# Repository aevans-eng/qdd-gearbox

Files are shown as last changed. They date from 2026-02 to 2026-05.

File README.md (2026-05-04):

# QDD Gearbox

A quasi-direct-drive actuator built around a D6374-150KV BLDC motor, a 5:1 3D-printed planetary gearbox, and an MKS xDrive Mini ODrive-compatible controller. Designed for backdrivability and impedance-control experiments. Total build cost under $120 CAD.

This is a personal engineering project tracked end-to-end with a real V&V framework: requirements, traceability matrix, test plans, and a documented test campaign. The goal is to learn actuator design from the physics up — and to produce something interview-grade for actuator-engineering roles.

## Status

**Rev 00B printed, assembled, and partially validated.**

| Test | Requirement | Status |
|---|---|---|
| T-012 backlash | R-01 | **Pass** — 0° measured |
| T-013 backdrivability | R-04 | Pending hockey-stick adapter |
| BOM weight | R-10 | Pending inspection |
| BOM cost | R-02 | Pending sum |
| T-020 peak torque | R-06 | Pending dyno day |
| T-021 continuous torque | R-07 | Pending dyno day |
| T-022 efficiency | R-09 | Pending — bare-motor baseline blocked, see [`testing/OFFICIAL-DYNO-TESTING.md`](testing/OFFICIAL-DYNO-TESTING.md) |
| T-023 speed | R-11 | Pending dyno day |
| T-024 thermal | R-08 | Pending dyno day |
| Health check (pre/post dyno) | R-05 | Pending |

Active blocker: bare-motor matched-load baseline against the trainer's loaded direction is torque-limited bare-motor. See [session-008 handoff](testing/data/session-008-bare-baseline-handoff.md) for the diagnosis and three options to unblock R-09.

## Hardware

| Component | Spec |
|---|---|
| Motor | D6374-150KV BLDC (7 pole pairs) |
| Torque constant | 0.04 Nm/A (conservative — used for all requirement math; nominal 0.0551 Nm/A documented but not yet re-validated) |
| Controller | MKS xDrive Mini (ODrive-compatible firmware), 8 kHz FOC |
| Gearbox | 5:1 planetary, 3D printed PLA, custom design |
| Supply | 24 V nominal, 10 A current limit, OVP 30 V, OCP 10 A |
| Encoder | Magnetic (integrated with controller) |
| Dyno | Saris H2 / Hammer trainer (BLE power + rpm) |
| Thermal monitoring | Arduino + thermistor on motor body, FET temp from controller |

Direction note: positive motor velocity drives the trainer's *loaded* (resistance-engaged) direction. Negative is freewheel. The bare motor at this controller's effective ~70 A Iq cap (≈ 2.8 Nm) cannot break the trainer's loaded-direction static drag — that's why the gearbox exists.

## How the Test System Works

The dyno runs are *synchronized*: motor controller, BLE dyno, and Arduino temperature logger all start within a second of each other and run for a fixed capture window. Output is one timestamped folder per run with:

- `motor.log` — controller telemetry (vbus, ibus, dc_W, Iq, encoder velocity, FET temp, phase currents)
- `dyno.csv` — Hammer rpm/power/torque from BLE
- `temperature.csv` — Arduino motor-body thermistor
- `manifest.json` — run metadata, parameters, summary stats, exit codes

Run a synced test:

```powershell
cd testing
.\run_official_requirement_test.ps1 -TestStage PreflightDirection
.\run_official_requirement_test.ps1 -TestStage BareBaseline -Series
.\run_official_requirement_test.ps1 -TestStage GearboxEfficiency -Series
```

See [`testing/OFFICIAL-DYNO-TESTING.md`](testing/OFFICIAL-DYNO-TESTING.md) for the full sequence, safety defaults, recovery procedures, and the bare-motor torque-limit constraint.

Compare a bare run against a gearbox-installed run:

```powershell
& C:\Users\aaron\miniconda3\python.exe .\analyze_synced_efficiency.py `
  --bare-run    .\data\synced-official-bare-baseline-40a-YYYYMMDD-HHMMSS `
  --gearbox-run .\data\synced-official-gearbox-efficiency-40a-YYYYMMDD-HHMMSS `
  --rpm-tolerance 3
```

## V&V Framework

11 requirements drive 7 tests + 3 inspections:

- **Source of truth:** [`testing/qdd-rtm.xlsx`](testing/qdd-rtm.xlsx) — full requirements traceability matrix.
- **Test log:** [`testing/validation/test-log.md`](testing/validation/test-log.md) — every test entry with date, config, result, anomalies.
- **Test plans:** [`testing/validation/`](testing/validation/) — per-test procedures, acceptance criteria.
- **Methodology:** test plan was redesigned around a V-model approach in March 2026.

Every test session also gets a journal entry in [`testing/data/session-log.md`](testing/data/session-log.md) and, for major sessions, a handoff doc (`session-NNN-*-handoff.md`) capturing what worked, what didn't, and what the next session needs to know.

## Repo Structure

```
calc/                 Python design calculators (gear geometry, tooth stress, bearing life, thermal)
docs/
  design/             Tolerances, assembly profile, gear parameters
  catia/              CATIA modeling guide and skeleton workflow
  log/                Session work logs
drawings/             GD&T annotation notes
prototypes/
  rev00a/             First print — superseded
  rev00b/             Current revision (assembled, partial validation passed)
testing/
  OFFICIAL-DYNO-TESTING.md     Operating procedures for the dyno campaign
  qdd-rtm.xlsx                 Requirements traceability matrix
  run_official_requirement_test.ps1   Wrapper for each requirement test stage
  run_synced_motor_dyno_temp.ps1      Underlying synced-capture orchestrator
  analyze_synced_efficiency.py        Match bare vs gearbox runs at common rpm windows
  plot_synced_run.py                  Per-run timeseries plots
  mks-xdrive-mini/                    Controller-side scripts and session checklist
  temperature-logger/                 Arduino + Python thermistor logger
  dyno/ble-capture/                   BLE Hammer capture
  validation/                         Per-test plans, test log, methodology docs
  hardware/                           Safety checklist, SOP, mounting notes
  data/                               Run folders + session-log.md + handoff docs
  future-work.md                      Characterization and controls ideas
STATE.md              Current project state — start here for any new session
CLAUDE.md             Project rules and conventions
```

## Active Files to Read First

- **[STATE.md](STATE.md)** — current status, remaining tests, file map, blockers.
- **[testing/data/session-008-bare-baseline-handoff.md](testing/data/session-008-bare-baseline-handoff.md)** — most recent test session, harness bug fixes, R-09 unblock options.
- **[testing/OFFICIAL-DYNO-TESTING.md](testing/OFFICIAL-DYNO-TESTING.md)** — dyno operating procedures.
- **[testing/qdd-rtm.xlsx](testing/qdd-rtm.xlsx)** — requirements ↔ tests matrix.

## License

Personal learning project. Not intended for redistribution.

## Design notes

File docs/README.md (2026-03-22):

# QDD Gearbox — Docs Index

## Design Reference
- `design/assembly-profile.md` — Assembly overview (living doc)
- `design/tolerance-scheme.md` — Tolerance scheme + FDM offsets
- `design/cycloidal-gear-params.md` — Involute vs cycloidal reference
- `design/motor-fastener-specs.md` — Motor fastener M3/M4 specs
- `design/tolerancing-discussion.md` — Assembly interface Q&A
- `design/non-parametric-shortcuts.md` — Hardcoded prototype decisions to fix later
- `design/manufacturing-tips.md` — DFM lessons

## CATIA Workflows
- `catia/step-integration.md` — STEP import workflow (the main doc)
- `catia/modeling-guide.md` — Modeling principles + assembly structure
- `catia/skeleton-workflow.md` — Practical skeleton workflows
- `catia/skeleton-step-current-state.md` — Confirmed STEP geometry values
- `catia/params-2026-02-20.txt` — Skeleton parameter dump (raw)

## Other
- `log/` — Dated work log entries
- `images/` — Screenshots and diagrams
- `original-documentation-jan4/` — Original design sprint docs (requirements, trade studies, etc.)
- `_archive/` — Old numbered docs (01-09), superseded

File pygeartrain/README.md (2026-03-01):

# pygeartrain



Python library for gear train calculations, visualizations, optimizations, and CAD profile export.

## Features

*   Symbolic calculation of gear ratios for various geartrain types.
*   Generation of 2D gear profiles (cycloidal, epi/hypo mix, involute - WIP).
*   Visualization and animation of geartrain kinematics using Matplotlib.
*   Export of gear profiles coordinates suitable for CAD import (e.g., SolidWorks).
*   Support for standard planetary, compound planetary (Wolfram), cycloidal, compound cycloidal, Nabtesco-style, and angular contact drives.

## Examples

Some examples of currently implemented gear trains:

**Compound Planetary (High Ratio)**<br />
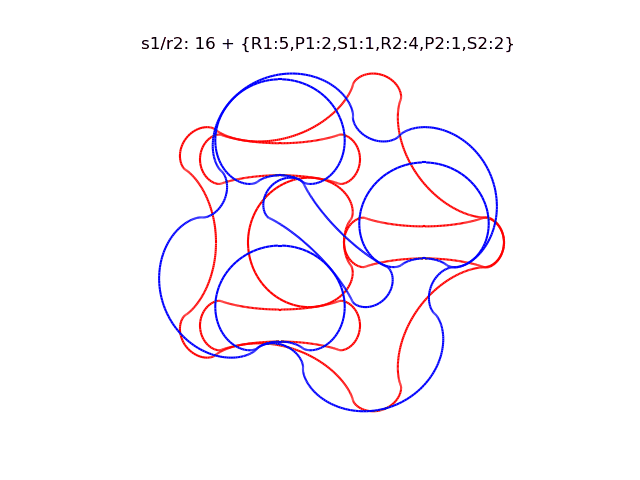
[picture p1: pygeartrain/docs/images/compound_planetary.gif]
Compound Planetary (High Ratio)
<br />

**Compound Planetary (Printable Low Count)**<br />
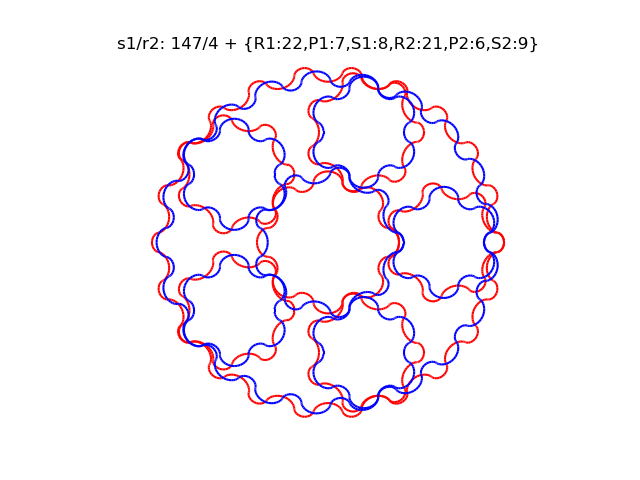
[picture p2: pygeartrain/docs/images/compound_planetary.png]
Compound Planetary (Printable Low Count)
<br />

**Angular Contact Drive**<br />
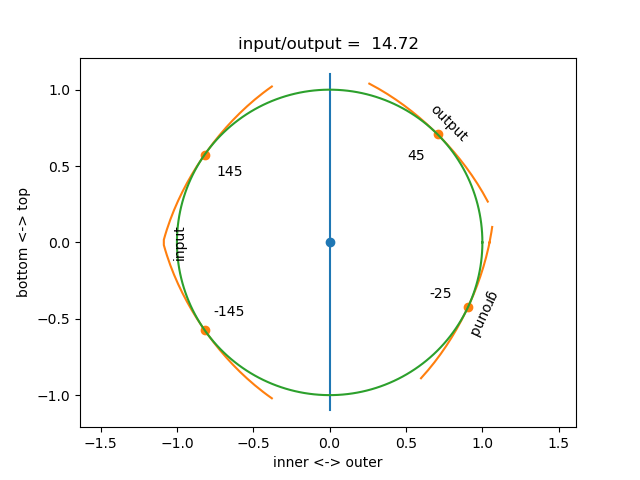
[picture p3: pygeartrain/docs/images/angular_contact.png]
Angular Contact Drive
<br />

**Cycloidal Drive**<br />
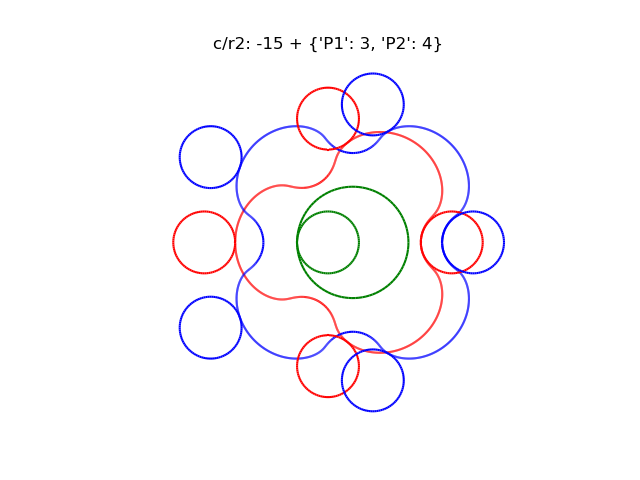
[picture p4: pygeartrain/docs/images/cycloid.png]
Cycloidal Drive
<br />

## Installation & Environment Setup

This project uses Conda for environment management.

**Prerequisites:**
*   [Conda](https://docs.conda.io/en/latest/) (Miniconda is recommended: [https://docs.conda.io/en/latest/miniconda.html](https://docs.conda.io/en/latest/miniconda.html))
*   [Git](https://git-scm.com/) (for cloning the repository)

**Steps:**

1.  **Clone the repository:**
    ```bash
    git clone https://github.com/CKraft11/pygeartrain pygeartrain
    cd pygeartrain
    ```

2.  **Create the Conda Environment:**
    Open your terminal or Anaconda Prompt in the `pygeartrain` directory (where `environment.yml` is located) and run:
    ```bash
    conda env create -f environment.yml
    ```
    *(Optional, faster alternative if you have Mamba installed: `mamba env create -f environment.yml`)*

3.  **Activate the Environment:**
    Each time you want to work with this project in a new terminal session, activate the environment:
    ```bash
    conda activate pygeartrain
    ```
    You should see `(pygeartrain)` appear at the beginning of your terminal prompt.

## Basic Usage: Calculating Ratios

You can define the kinematics of a geartrain and calculate its ratio symbolically:

```python
from pygeartrain.planetary import Planetary

# Define kinematics: Input='s' (sun), Output='c' (carrier), Fixed='r' (ring)
kinematics = Planetary('s', 'c', 'r')

# Print the kinematic definition and the calculated ratio formula
print(kinematics)
# >>> s/c: (R + S)/S
```

## Advanced Usage: Generating CAD Profiles for SolidWorks

Right now I've made `generate_planetary_cad.py` which only works for planetary gears. Generating the other gear types shouldn't be too hard following this script.

**1. Configuration:**

   Open the `generate_planetary_cad.py` script in a text editor. Modify the parameters in the "**User Defined Parameters**" section near the top:

   *   `TARGET_RING_DIAMETER_MM`: Set the desired outer diameter (in mm) for the final scaled ring gear. All other gears are scaled proportionally.
   *   `GEAR_THICKNESS_MM`: Set the total face width (along the Z-axis) for the gears.
   *   `HELIX_ANGLE_DEGREES`: Define the helix angle (in degrees) for one side of the gear tooth (used for both helix and herringbone).
   *   `GEAR_TYPE`: Choose `'helix'` for standard helical gears or `'herringbone'` for double-helical (V-shaped) gears.
   *   `R_teeth`, `P_teeth`, `S_teeth`: Set the tooth counts for the Ring, Planet, and Sun gears. Ensure they satisfy the planetary assembly condition: `R = S + 2*P`.
   *   `N_planets`: Set the number of planet gears around the sun.
   *   *(Optional)* `b_profile`: Adjust the epi/hypo cycloid mix ratio (0 to 1) for the tooth shape.
   *   *(Optional)* `CARRIER_PATH_POINTS`: Number of points for the exported circular carrier path file.
   *   *(Optional)* `CLOSE_POINT_TOLERANCE`, `SMALL_RADIUS_TOLERANCE`: Adjust point filtering sensitivity if needed.

**2. Running the Export Script:**

   Make sure the `pygeartrain` environment is active (`conda activate pygeartrain`). Run the script from the main project directory:

   ```bash
   python generate_planetary_cad.py
   ```

**3. Understanding the Output:**

   The script will create a directory named `output_helix` or `output_herringbone` containing several `.txt` files:

   *   **Gear Profile Curves:** 9 files for the gear teeth, 3 for each gear type (ring, planet, sun).
        *   `*_z0.txt`: The profile curve at the center plane (Z=0).
        *   `*_z_pos.txt`: The profile curve twisted for the +Z face (at Z = +thickness/2).
        *   `*_z_neg.txt`: The profile curve twisted for the -Z face (at Z = -thickness/2).
        *(The twist direction and type depend on the `HELIX_ANGLE_DEGREES` and `GEAR_TYPE` settings, with meshing hands automatically adjusted).*
   *   **Carrier Path:** 1 file:
        *   `carrier_path.txt`: A simple circle representing the path of the planet gear centers, useful for positioning planets in an assembly. Lies in the Z=0 plane.

   All coordinates in the files are in millimeters, scaled according to `TARGET_RING_DIAMETER_MM`.

**4. Importing into SolidWorks:**

   *  Create a new SolidWorks Part file.
   *  Import the 3 curves for **one gear** (e.g., `ring_21_z_neg.txt`, `ring_21_z0.txt`, `ring_21_z_pos.txt`):
       *   Go to **Insert > Curve > Curve Through XYZ Points**.
       *   **Browse** and select the first file (e.g., `_z_neg.txt`). Click **OK**.
       *   Repeat for the `_z0.txt` and `_z_pos.txt` files of the *same gear*. The curves should appear positioned correctly in 3D space.
   *  Select the three imported curves for that gear in the FeatureManager Design Tree.
   *  Click point in reference geometry and select one of the imported curves (do this for all 3 curves)
   *  Create a 3D sketch with two lines between the 3 points you just added in order to create a loft guide. You shoud have something looking like this.
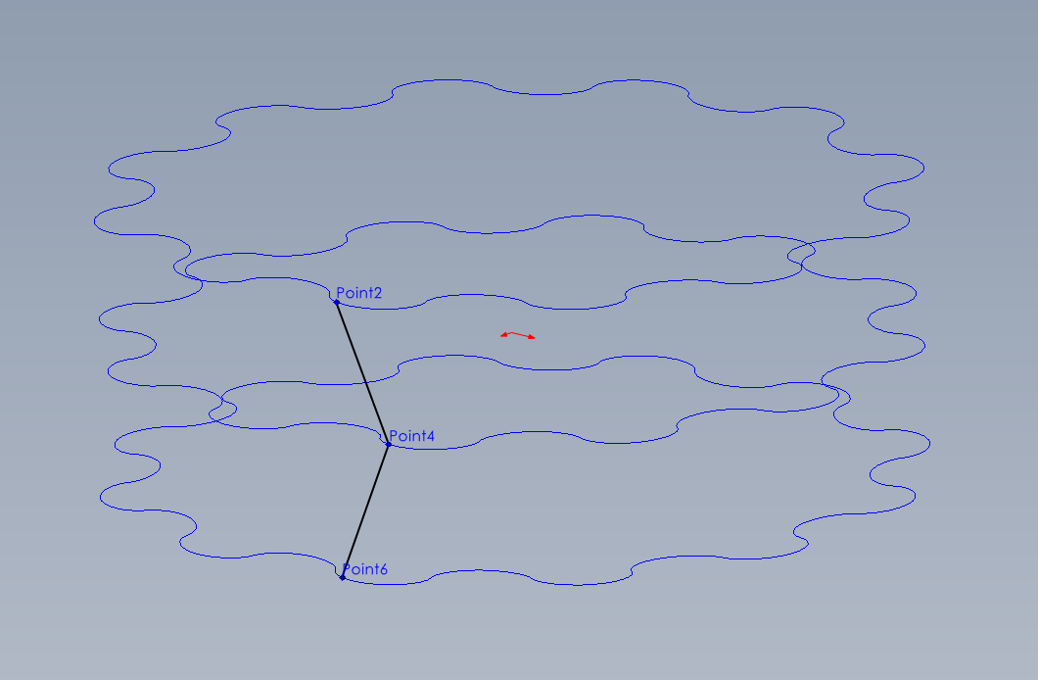
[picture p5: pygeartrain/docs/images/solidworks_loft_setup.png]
Solidworks Loft Setup
   
   *  Create the gear body by creating two lofts separatly for either side using **Insert > Boss/Base > Loft** (or **Insert > Surface > Loft**). Use the 3D sketch as a guide for both of them.
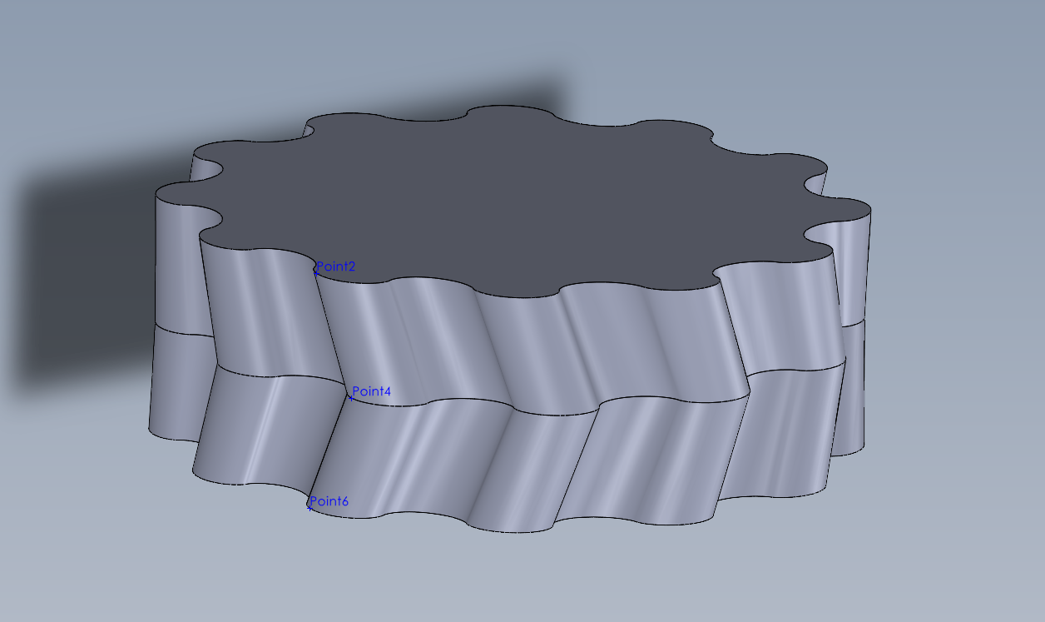
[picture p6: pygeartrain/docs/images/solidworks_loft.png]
Solidworks Loft Setup
   
   *  Repeat steps for the Sun and Planet gears using their respective curve files.
   *  **For the Planet:** After creating the single lofted planet gear body, use the **Circular Pattern** feature (**Insert > Pattern/Mirror > Circular Pattern**) to create `N_planets` instances around the part origin.
   *  **Carrier Path (Optional):** Import `carrier_path.txt` onto a sketch on the Front Plane (Z=0) using **Insert > Curve > Curve Through XYZ Points**. Solidworks doesnt recognize this as a circle so you can create a circle on the XY plane and set it to have a point coincident to the carrier path curve. This circle can be used as a construction reference for designing the physical carrier or for assembly mates.

## Animation

The geometry objects generated by the library (like `PlanetaryGeometry`) often have an `.animate()` method. You can call this in your script (after creating the `gear` object) to visualize the kinematic motion using Matplotlib.

```python
# Assuming 'gear' is a created PlanetaryGeometry object
# gear.animate() # Call this instead of static plotting
# plt.show() # Not needed if calling animate()
```

*Note: The animation shows the **unscaled** gear profiles to verify meshing and relative speeds based on the kinematics.*

## License

This project is licensed under the MIT License - see the [LICENSE](LICENSE) file for details.

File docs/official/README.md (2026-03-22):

# Official Documentation

Portfolio-ready and publication-ready content for the QDD Gearbox project.

| File | Purpose |
|---|---|
| `website-content-bank.md` | Consolidated text content for the portfolio page — all sections, tables, specs |
| `media-next-steps.md` | Checklist of photos, renders, graphs, and diagrams still needed |

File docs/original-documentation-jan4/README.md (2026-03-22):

# Design Sprint — Jan 4, 2026

Organized reference from the original hackathon Google Doc where the QDD actuator project was scoped, designed, and kicked off in a single day.

## Contents

| File | What's in it |
|---|---|
| `goals-and-scope.md` | Project objectives, definition of done, in/out scope |
| `design-requirements.md` | Ranked priorities, quantified metrics, hard vs soft requirements |
| `systems-and-interfaces.md` | System block diagram, subsystem definitions, interface strategy |
| `trade-studies.md` | Pugh matrices for reduction method, gear ratio, and bearings |
| `design-process.md` | The step-by-step design process used that day |
| `parts-list.md` | Fasteners, bearings, tools — what was sourced |
| `prototype-strategy.md` | 3D modeling strategy, assembly stack, initial design notes |
| `references.md` | External links |

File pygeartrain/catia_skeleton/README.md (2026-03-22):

# CATIA Planetary Gearbox Skeleton Generator

Creates reference geometry for planetary gearbox design in 3DExperience CATIA.

## Status: WORKING

![[photos/skeleton-working-result.png]]
*Wireframe skeleton*

![[photos/skeleton-with-cylinders.png]]
*Solid cylinders generated from skeleton*

## Workflow

| Version | File | Purpose | Status |
|---|---|---|---|
| **Bounding Cylinders** | `PlanetarySkeletonGenerator.bas` | Quick visualization with solids | Untested |
| **True Skeleton** | `PlanetarySkeletonTrue.bas` | Wireframe for skeleton-first design | **WORKING** |

**Recommendation:** Use True Skeleton for any real design work.

## Key Learnings (2026-01-31)

### 3DExperience VBA Differences

1. **Get active part:** Use `CATIA.ActiveEditor.ActiveObject` (NOT `CATIA.ActiveDocument`)

2. **Create circles:** `AddNewCircleCtrRad` requires 4 arguments:
   ```vba
   ' WRONG (3 args - fails silently)
   hsFactory.AddNewCircleCtrRad(center, plane, radius)

   ' CORRECT (4 args - geodesic boolean required)
   hsFactory.AddNewCircleCtrRad(center, plane, False, radius)
   ```

3. **Create axes:** `AddNewLinePtDir` works with 5 args:
   ```vba
   hsFactory.AddNewLinePtDir(point, direction, startLength, endLength, False)
   ```

4. **Direction from plane:** Get Z-direction by passing XY plane to `AddNewDirection`:
   ```vba
   Set dirZ = hsFactory.AddNewDirection(part.OriginElements.PlaneXY)
   ```

## Files

| File | Purpose |
|---|---|
| `PlanetarySkeletonTrue.bas` | Step 1: Creates wireframe skeleton |
| `SkeletonToCylinders.bas` | Step 2: Pads circles into solid cylinders |
| `PlanetarySkeletonGenerator.bas` | Alt: Bounding cylinders (untested) |
| `Skeleton Generator Walkthrough.md` | Detailed usage guide |
| `photos/` | Screenshots |

## Quick Start

1. Open a new **3D Part** in 3DExperience
2. Make sure part is in edit mode (double-click if needed)
3. Press `Alt+F8` → Macros → Select → `PlanetarySkeletonTrue.bas` → Run
4. Run again with `SkeletonToCylinders.bas` to create solid bodies

### Generated Geometry

```
Skeleton (Geometrical Set)
├── POINT_ORIGIN
├── AXIS_SUN
├── CIRCLE_PITCH_SUN (r=7mm)
├── CIRCLE_PITCH_RING (r=35mm)
├── CIRCLE_OUTER_RING (r=40mm)
├── CIRCLE_ORBIT (r=21mm)
├── POINT_PLANET_1, _2, _3
├── AXIS_PLANET_1, _2, _3
└── CIRCLE_PITCH_PLANET_1, _2, _3 (r=14mm)
```

### Customizing Dimensions

Edit these variables at the top of the macro:
```vba
Dim SunPD As Double: SunPD = 14       ' Sun pitch diameter
Dim PlanetPD As Double: PlanetPD = 28 ' Planet pitch diameter
Dim RingPD As Double: RingPD = 70     ' Ring pitch diameter
Dim RingOD As Double: RingOD = 80     ' Ring outer diameter
Dim OrbitR As Double: OrbitR = 21     ' = (SunPD + PlanetPD) / 2
```

## Planetary Gear Validation

For proper mesh: `RingTeeth = SunTeeth + 2 × PlanetTeeth`

Example (HackathonActuator): 30 = 6 + 2×12 ✓

## Roadmap

### Next: Additional Components
- [ ] Carrier disc with planet bores
- [ ] Carrier pins (cylinder at each planet axis)
- [ ] Bearing cylinders (ID/OD representation)
- [ ] Input/output shaft cylinders

### Future: Parametric Enhancements
- [ ] CATIA parameters (edit in tree instead of macro)
- [ ] Formulas for derived dimensions
- [ ] Publications for external linking
- [ ] Top/bottom planes for extrusion limits

## Related

- [[CATIA XYZ Import Progress]] - Import actual gear tooth profiles
- [[HackathonActuator]] - Gearbox this was developed for

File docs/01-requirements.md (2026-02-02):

# QDD Actuator — Design Requirements

## Project Goal

Create a quasi-direct-drive actuator by designing a 3D-printable gearbox to interface with a BLDC motor, magnetic encoder, and ODrive controller.

## Primary Objective

Reach "Manufacturing Readiness" — complete CAD assembly, locked BOM, and all COTS components ordered.

## Secondary Objective

Complete "Design Intent" documentation (justification for ratio, motor choice, materials).

## Scope

### In-Scope

- Mechanical design of a reduction stage (gearbox) optimized for FDM 3D printing
- Integration of a specific BLDC motor, magnetic encoder, and ODrive controller
- Interface design of the housing and output interface
- Basic modeling of the control system

### Out-of-Scope

- Custom motor winding or controller PCB design
- Complex firmware coding (basic ODrive config is assumed)
- Exotic manufacturing (no CNC aluminum; design must be printable)

## Performance Requirements (Ranked by Priority)

| # | Requirement | Metric | Hard/Soft |
|---|---|---|---|
| 1 | Low Backlash | ≤ 0.5° of backlash | Hard |
| 2 | Low Cost | Under $120 CAD | Hard |
| 3 | DFM/DFA | All off-the-shelf + 3D printed parts. No complex tools for assembly | Hard |
| 4 | Quasi-Direct Drive | Backdriveable under human impulse loading | Hard |
| 5 | High Durability | Cannot break itself in under 1 minute (SW + HW limits) | Hard |
| 6 | Peak Torque | ≥ 16 Nm peak | Hard |
| 7 | Continuous Torque | ≥ 12 Nm continuous | Hard |
| 8 | Output Integration | Supports shafts or bolted plates | Soft |
| 9 | Thermal Performance | No melting in < 5 minutes | Hard |
| 10 | Efficiency | > 90% | Soft |
| 11 | Weight | Under 2 kg | Soft |
| 12 | RPM Range | ≥ 600 RPM continuous | Soft |

## What Makes a QDD Different

A QDD is not a regular geared motor. If the gearbox has high friction or backlash, it is not a QDD — it must be backdrivable. **Transparency** and **backlash** are the defining characteristics.

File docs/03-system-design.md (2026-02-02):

# QDD Actuator — System Design

## System Block Diagram

Power Supply → ODrive ESC → BLDC Motor → Input Coupling → Gear Reduction → Output Coupling → Load
                  ↑
               Encoder (feedback to ESC)
               Brain (commands to ESC)

## Subsystem Definitions

### Power Supply
- **Input:** Wall power
- **Purpose:** Provide electrical power to ESC
- **Output:** Conditioned DC power to ESC

### Brain
- **Purpose:** Tells the ESC what to do
- **Input:** User commands
- **Output:** Signal to ESC

### ODrive ESC
- **Purpose:** Control motor
- **Input:** Conditioned DC power, signal from brain
- **Output:** Motor winding current

### BLDC Motor
- **Purpose:** Torque to coupling
- **Input:** Current from ESC
- **Output:** Torque

### Encoder
- **Purpose:** Sensing for control system
- **Input:** Coupled to motor
- **Output:** Signal to ESC

### Input Coupling
- **Purpose:** Couples motor to gearbox
- **Input:** Motor shaft
- **Output:** Gearbox input
- **Options considered:** Press fit, screw collar, keyed shaft

### Gear Reduction
- **Purpose:** Increase torque
- **Input:** Coupling
- **Output:** Output coupling

### Output Coupling
- **Purpose:** Control output arm
- **Input:** Gearbox output
- **Output:** Control arm
- **Considerations:** Size, fastening methods, supported vs unsupported bearing interaction

## Critical Interfaces

1. **Thermal Interface:** Motor to mount
2. **Mechanical Interface:** Output shaft to load
3. **Data Interface:** Magnet position relative to encoder chip

## Control Strategy

Confirm ODrive control mode (Position vs. Velocity vs. Torque) matches the mechanical design. Verify encoder resolution is sufficient for the gear reduction.

## Key Design Lesson

> The #1 failure mode in student robotics projects is not the gearbox itself, but how the gearbox attaches to the motor or how the magnet attaches to the shaft. — Interface definition is critical.

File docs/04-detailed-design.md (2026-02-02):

# QDD Actuator — Detailed Design & CAD

## 3D Modeling Strategy

- Master assembly designed to be modular with different gearing layouts, minimizing iteration time
- Sun, planet, and ring gears are interlinked but should be independent systems
- Carrier designed to be parametric with the gear systems — always compatible
- Ring gear modular from gearbox housing — easily swappable for prototyping
- Housing may need two parts: ring gear installs into housing, carrier sits under planets
- Sun, planet, and ring to be printed together

## Assembly Stack (Bottom → Top)

1. Bottom housing face
2. Housing bottom carrier bearing
3. Bottom carrier plate
4. Sun gear on shaft, planet gears aligning with bottom carrier plate and pins, ring gear slides into housing
   - Planet gears
5. Top carrier plate
6. Ring gear locking feature
7. Lid top carrier bearing
8. Lid

## Parts to Design

- Housing that bolts to motor
- Sun gear that interfaces with motor output
- Planet gears
- Ring gear with output connection
- Lid

## Design for Manufacturing (DFM)

- Apply printing tolerances (offsets)
- Design orientation features (avoid supports on gear faces)
- Virtual assembly in CAD to catch interference

## Design Calculators Needed

- Bearing placement calculator
- Bearing lifetime calculator
- Involute teeth stress calculator
- Cycloidal teeth stress calculator
- Shear on pins/screws calculator

## CAD Creation Pipeline (Parallel Tasks)

1. Get gear teeth generator working
2. Make arbitrary gearset to try out different input and output strategies

## Design Decision: 5:1 Ratio Maintained

Decision was made to maintain 5:1 gear ratio based on trade study results (see 02-trade-studies.md).

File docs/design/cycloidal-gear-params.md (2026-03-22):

# Cycloidal Gear Parameter Reference

How to think about cycloidal planetary gear dimensions when coming from an involute background.
Applies to this project: R48/P18/S12, pygeartrain, herringbone, scaled to 75mm ring ID.

---

## Involute vs Cycloidal — Parameter Comparison

| Parameter | Involute | Cycloidal |
|---|---|---|
| **Module** | $m$ — sets tooth scale, $d = m \times N$ | **N/A — delete this parameter.** Tooth scale is set by specifying ring diameter + tooth counts. Do not set to zero (breaks formulas). |
| **Pitch diameter** | Clean definition: $d = m \times N$, the reference circle where teeth mesh | No clean equivalent. Use **outer diameter (tip circle)** as the functional reference for skeleton checks. Carrier radius = `(ring_pitch_diam - planet_outer_diam) / 2` — planet tips are tangent to ring tooth roots which sit at the pitch reference. |
| **Tooth depth** | $2.25m$ (standard full depth) | Falls out of rolling circle geometry. Cannot be calculated from a simple formula — **measure from STEP in CATIA.** |
| **What sets the scale** | Module | Target ring inner diameter + tooth counts (R, P, S) |
| **What you specify** | $m$, $N$, pressure angle | $R$, $P$, $S$, ring diameter, face width |

---

## This Project's Dimensions (Run 001 STEP files)

From `generate_step_aaron.py` output and `catia/step-integration.md`:

| Part | Dimension | Value | What it is |
|---|---|---|---|
| Sun | Outer diameter | 19.9mm | Tip circle — largest solid extent |
| Planet | Outer diameter | 29.1mm | Tip circle — largest solid extent |
| Planet | Center-to-axis distance | 23.0mm | Carrier radius — where planet center sits |
| Ring | Inner reference diameter | 75.0mm | Pitch reference / engagement zone |
| Ring | Outer diameter | 95.0mm | OD — fits in housing bore (95.3mm, 0.3mm clearance) |
| Ring | Nominal wall | 10.0mm | From 75mm ID reference to 95mm OD — **includes tooth depth** |
| Ring | Solid wall (root to OD) | **Measure in CATIA** | Less than 10mm — see below |
| All gears | Face width | 18.6mm | Axial thickness |

---

## The Ring Gear Wall Problem

`RING_WALL_MM = 10mm` in the script is measured from the **pitch reference radius (37.5mm) to the outer cylinder (47.5mm).**

The tooth roots cut *outward* from the pitch reference, eating into that 10mm. The actual solid wall between the deepest tooth root and the OD is less than 10mm.

**To get the real solid wall:**
1. Import `gearbox_CAD.step` into CATIA
2. Section view through the ring gear (section on the gear midplane)
3. Pick a tooth root face (the outermost point of the internal tooth profile)
4. Measure radial distance from that face to the OD cylinder
5. Record that number — it's the minimum solid wall for fastener and structural design

**Why this matters for the skeleton:**
- Fastener holes through the ring wall must stay radially outside the tooth root circle
- The skeleton parameter `ring_wall_thickness = 10mm` is the nominal design wall, not the solid wall
- Don't position fastener hole centers using 10mm as the solid material — wait for the STEP measurement

---

## Skeleton Parameter Updates (Old Involute → New Cycloidal)

Changes to make in SKEL_Gearbox before importing STEP:

| Skeleton Param | Action | New Value | Priority |
|---|---|---|---|
| `planet_mid_path` | Update | **23.0mm** | Critical — drives bearing pocket placement |
| `planet_pitch_diam` → rename to `planet_outer_diam` | Update | **29.1mm** | Important — drives clearance checks |
| `sun_pitch_diam` → rename to `sun_outer_diam` | Update | **19.9mm** | Minor — 0.1mm change |
| `gear_module` | **Delete** | N/A | Do not set to zero |
| `ring_pitch_diam` | No change | 75mm | Already correct |
| `gear_height` | No change | 18.6mm | Already correct |
| `ring_wall_thickness` | No change (for now) | 10mm | Verify actual solid wall after STEP import |
| `housing_ring_gear_bore` | No change | 95.3mm | Already correct |

---

## Notes

- For pygeartrain cycloidal gears, "pitch diameter" and "outer diameter" are not the same thing, but outer diameter is the useful number for physical fit checks in CATIA.
- The gear ratio is still $\frac{R + S}{S} = \frac{48 + 12}{12} = 5:1$ — same math as involute.
- Tooth counts R/P/S fully define the geometry proportions; ring diameter sets the scale.

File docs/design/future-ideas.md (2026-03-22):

# Future Design Ideas

Notes on potential improvements for future revisions.

## Slimmer Bearing → Smaller Housing
- Switch bottom bearing to a thinner, wider variant
- Reduces total gearbox height
- **Must verify:** radial stress and fatigue via hand calcs
- **Constraint:** lower bearing cannot interfere with fastener threads

## Ring Gear as Housing ("Hamburger" Layout)
- Drop housing walls down to same diameter as ring gears
- Ring gears become the structural middle of the gearbox (like a hamburger patty)
- Eliminates the current approach of ring gear sitting *inside* the housing
- Combined with slimmer bearings, significantly reduces form factor

## Carrier Fastening & Planet Shaft Strategy
- **Option A: Shoulder bolts** — dual-purpose as carrier half constraints and planet bearing shafts
- **Option B: Pins + fasteners** — dedicated pins for planet bearing shafts, separate fasteners to connect carrier halves
- Worth exploring trade-offs (assembly complexity, tolerance stack, load path, part count)

## Integrated Motor + Controller Package
- Future iteration: combine gearbox with a 3D-printed motor housing
- Single package houses motor controller, brake resistor, and encoder

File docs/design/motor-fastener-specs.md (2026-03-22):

Motor housing-lid fasteners
m3 x 8mm, cap head (-motor housing)
- 5mm thread engagement
- Head height is 3.25mm
- available lengths: 8mm, 12mm, 16mm, 20mm
- 
m4 x 6mm button head (-motor)
- 4mm thread engagement 
- Head height is 3.5mm
- MAX THREAD ENGAGMENT SHOULD BE 4mm, longer threads can result in damage to motor
- at most counterbore should be baseheight - counterbore = (fastener length-engagement), counterbore = baseheight +engagement - fastener length

with 6mm lid height
4mm m4 counterbore
3mm m3 counterbore

currently, the fastener holes for body to motor and motor housing are NOT parametric.

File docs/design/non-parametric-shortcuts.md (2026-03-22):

# Non-Parametric Shortcuts — Prototype Debt

Things hardcoded or done in haste for the prototype that will break if design parameters change. Fix these before any serious design iteration.

---

## Gear Cutting Bodies — Hardcoded to 3 Planets

The `cutting/adding bodies` part has 3 separate cutting body entities, one per planet. CATIA can't (as far as we know) apply one cutting body to multiple target entities, so the count is manually matched to `number_of_planets = 3`.

**Breaks if:** planet count changes (e.g. 4 planets → need a 4th cutting body manually added).

**Proper fix:** Investigate if CircPattern or body-level patterning can drive cutting bodies from `number_of_planets`. If not, at minimum document the manual step clearly so it's not forgotten during a redesign.

---

## Housing Base Fasteners — Fixed Counts

Some housing base fastener holes are set to fixed numbers rather than driven by a parameter or pattern.

**Breaks if:** fastener layout changes (different bolt count or pattern).

**Proper fix:** Drive from skeleton parameter + circular/rectangular pattern.

---

## Motor Housing Fasteners — Not Parametric

From `motor-fastener-specs.md`: "currently, the fastener holes for body to motor and motor housing are NOT parametric."

**Breaks if:** motor changes, lid thickness changes, or fastener spec changes.

---

*Add more shortcuts here as you notice them. Review before any major design change.*

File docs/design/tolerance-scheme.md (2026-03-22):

# Tolerance Scheme — QDD Planetary Gearbox

Every mating interface in the gearbox, with fit types, tolerance values, and critical stack-ups. Bridges ISO/ASME fit standards (for learning) with FDM-practical values (for implementation).

**Status:** Post-calibration v1 — applying coupon results to CATIA parameters. Planet gear print queued to validate bearing bore offset with a real part. Small hole offsets are approximate — planet print tests the critical bearing fit, remaining small features validated later.

**Key design facts (from discussion):**
- Lid step presses down onto ring gears (axial constraint)
- Ring gears slide into cylindrical housing bore, split at mid-height
- Shoulder screws = planet pins + carrier fasteners
- Carrier sits on bottom main bearing via lip; lid bearing catches top carrier
- Sun gear: press fit onto D-shaft (circle with flat)
- Herringbone planets: self-centering axially, floating
- No post-processing planned — everything as-printed
- Calibration coupon v1 printed 2026-02-19 — main bearing fit validated, planet bore and small holes need offset corrections
- CATIA parameters being updated with calibration-derived offsets (2026-02-20)

**Related docs:**
- `_archive/08-gdt-notes.md` — Datum reference frame and GD&T callouts
- `_archive/05-parts-list.md` — BOM with bearing/fastener specs
- `tolerancing-discussion.md` — Design Q&A (completed)

---

## Background: How ISO Fits Work

If you've never worked with ISO tolerance designations before, this section explains the system. Everything below in the interface tables will make more sense after reading this.

### The Problem Fits Solve

When two parts mate — a shaft going into a hole — you need to control how tight or loose that joint is. Too loose and things rattle. Too tight and you can't assemble it (or you crack the part). The ISO system gives engineers a standardized language to specify exactly how much clearance or interference a joint should have.

### Anatomy of a Designation: H7/k6

Every fit designation has two parts: **hole / shaft**.

```
    H  7  /  k  6
    │  │     │  │
    │  │     │  └── Tolerance grade (how precise the shaft must be)
    │  │     └───── Fundamental deviation (where the shaft sits relative to nominal)
    │  └────────── Tolerance grade (how precise the hole must be)
    └───────────── Fundamental deviation (where the hole sits relative to nominal)
```

### The Letter: Fundamental Deviation (Position)

The letter tells you **where** the tolerance zone sits relative to the nominal (exact) dimension.

**For holes** (uppercase letters):
```
                     Nominal
                        │
  A  B  C  D  ... G  H │ J  K  ... N  P  R  S  ...  Z
  ◄─── larger ─────────►│◄─── smaller ──────────────►
        (more clearance) │      (more interference)
```

**For shafts** (lowercase letters):
```
                     Nominal
                        │
  a  b  c  d  ... g  h │ j  k  ... n  p  r  s  ...  z
  ◄─── smaller ────────►│◄─── larger ──────────────►
        (more clearance) │      (more interference)
```

**Key letters to know:**

| Letter | Meaning |
|---|---|
| **H** (hole) | Starts exactly at nominal, goes up. The most common hole designation — "hole basis" system |
| **h** (shaft) | Starts exactly at nominal, goes down. Shaft at or below nominal |
| **g** (shaft) | Below nominal — guaranteed clearance in an H hole |
| **k** (shaft) | Straddles nominal — might be slightly above or below. Transition zone |
| **p** (shaft) | Above nominal — guaranteed interference in an H hole |

### The Number: IT Grade (Precision)

The number (called the **IT grade**) controls **how wide** the tolerance band is — i.e., how precisely the part must be made.

| IT Grade | Typical Tolerance at ⌀25mm | Used For |
|---|---|---|
| IT5 | ±0.004mm | Precision ground shafts |
| IT6 | ±0.006mm | Ground/precision turned shafts |
| IT7 | ±0.010mm | Reamed holes, good machining |
| IT8 | ±0.013mm | Standard machining |
| IT11 | ±0.065mm | Rough machining |
| IT14+ | ±0.26mm+ | Sheet metal, casting, **FDM printing** |

**Lower number = tighter tolerance = more expensive to make.**

For our QDD project, standard machining fits (IT6/IT7) describe what we *want* the joint to behave like. The FDM offsets in this doc are how we *approximate* those fits with 3D printing.

### The Three Fit Categories

When you combine a hole and shaft designation, you get one of three fit types:

```
  ┌──────────────┬──────────────┬──────────────┐
  │  CLEARANCE   │  TRANSITION  │ INTERFERENCE  │
  │              │              │               │
  │  Shaft       │  Shaft       │   ████████    │
  │  ┌──────┐    │  ┌───╫──┐   │  ┌██████──┐   │
  │  │      │    │  │   ║  │   │  │████████ │   │
  │  │ gap  │    │  │   ║  │   │  │████████ │   │
  │  │      │    │  │   ║  │   │  │████████ │   │
  │  └──────┘    │  └───╫──┘   │  └██████──┘   │
  │   Hole       │   Hole       │   Hole        │
  │              │  may be      │   shaft is    │
  │  always a    │  clearance   │   larger      │
  │  gap         │  or press    │   than hole   │
  └──────────────┴──────────────┴──────────────┘
```

| Category | Example | Shaft vs Hole | Typical Use |
|---|---|---|---|
| **Clearance** | H7/g6 | Shaft always smaller | Sliding/rotating parts, easy assembly |
| **Transition** | H7/k6 | Could go either way | Locating bearings in stationary housings |
| **Interference (Press)** | H7/p6 | Shaft always larger | Locking parts together, bearing on rotating shaft |

### Fits Used in This Gearbox

Here's every fit in this doc mapped to why it was chosen:

| Interface | Fit | Category | Reasoning |
|---|-----|---|---|
| Bottom bearing ID → Housing shaft | k6 | Transition | Housing is stationary — inner race sits snug on shaft |
| Bottom bearing OD → Carrier bore | H7/k6 | Transition | Finger press — FDM texture prevents creep, maximizes backdrivability |
| Top bearing OD → Lid bore | H7/k6 | Transition | Lid is stationary — bearing should sit snug but be hand-assemblable |
| Carrier output shaft → Top bearing ID | k6 | Transition | Finger press — matches gold standard feel |
| Planet bearing → Planet gear bore | H7/k6 | Transition | Finger press — same feel as main bearing, validates with planet print |
| Shoulder screw → Planet bearing ID | g6 | Clearance | Pin is stationary — bearing spins freely on it |
| Ring gear → Housing bore | H7/h6 | Clearance | Ring drops in for assembly, lid holds it axially |
| Sun gear → Motor shaft | H7/p6 | Press fit | Must transmit full motor torque without slipping |
| Lid step → Housing bore | H7/h6 | Clearance | Self-centering fit, must be assemblable |

### "Hole Basis" System

You'll notice every hole above is **H** (or the bore is the reference). This is the **hole basis** system — you make the hole to a standard size and adjust the shaft to get the fit you want. This is the most common approach because:

1. Holes are harder to adjust after manufacturing (especially bored/reamed holes)
2. Shafts are easier to turn down or grind
3. For bearings, the bore/OD is fixed by the manufacturer — you adjust the housing bore and shaft to match

### How This Connects to FDM

ISO fits assume machined metal parts with micron-level control. FDM printing operates at ±0.1-0.3mm — orders of magnitude looser. So we can't achieve a true H7/k6, but we can use the *intent* of each fit:

| ISO Intent | What We Do in FDM |
|---|---|
| Transition fit (snug, assemblable) | Oversize bore by 0.10mm — printing shrinks it to approximately snug |
| Press fit (locked together) | Model at nominal or slight interference — printing creates natural press |
| Clearance fit (slides freely) | Oversize bore by 0.2-0.3mm — ensures parts slide together despite FDM variation |

The ISO designations in this doc serve two purposes:
1. **Learning** — you know what fit an engineer would specify for each interface
2. **Intent** — the FDM offsets are calibrated to approximate that behavior

---

## How to Read This Document

| Field | Meaning |
|---|---|
| **Function** | What this fit needs to accomplish |
| **ISO Designation** | Standard fit code (e.g., H7/g6) — for learning/documentation |
| **Nominal** | The bearing/component dimension (fixed by manufacturer) |
| **CATIA Today** | What the skeleton currently models this as |
| **FDM Target** | What we should model to get a good as-printed fit |
| **New Parameter** | Parameter to add to skeleton for the clearance/offset |
| **Priority** | Critical / Important / Standard |

**FDM offset convention:** Bores print smaller than modeled. Shafts print larger than modeled. So:
- Bores: model **oversized** (add clearance to nominal)
- Shafts: model **undersized** (subtract clearance from nominal)

---

## FDM Bearing Fit Philosophy

**Decision (2026-02-20):** All bearing interfaces target a **finger-press transition fit** — the same feel as the main bearing in calibration coupon v1 (⌀37.10mm bore, 6805-2RS pushed in by hand with firm finger pressure).

### Why we departed from convention

The textbook rule is: *the rotating ring gets an interference/press fit* to prevent bearing creep (race slowly spinning in its housing). For machined metal parts with micron-level control, this is correct and important.

**For our 3D-printed QDD, the priorities are different:**

| Factor | Convention says | Our situation |
|---|---|---|
| Fit precision | Achievable to ±0.01mm | FDM gives ±0.1-0.3mm — can't achieve true press fits reliably |
| Top priority | Bearing life, load capacity | **Backdrivability** — friction kills the whole QDD concept |
| Axial loads | Depend on gear geometry | Herringbone gears self-center → minimal axial thrust on bearings |
| Load level | Often high, continuous | Low torque, prototype loads |
| Surface texture | Smooth metal needs interference for grip | FDM layer lines provide natural grip even in transition fits |
| If creep occurs | Catastrophic in production | Fixable — loctite retaining compound or reprint with offset tweak |

### The rule for this gearbox

**Every bearing interface targets the coupon v1 main bearing feel:** firm finger press, clicks into place, doesn't fall out. This applies to both stationary and rotating rings.

The ISO designations in this doc still show what a conventional engineer would specify — for learning. The FDM offsets implement the transition-fit-everywhere strategy.

---

## 1. Radial Fits (Bore/Shaft Interfaces)

### 1.1 Bottom Main Bearing ID → Housing Body Shaft

> 6805-2RS inner race (⌀25mm) sits on a shaft/boss on the housing body

| Field | Value |
|---|---|
| **Function** | Housing body shaft locates the bottom bearing radially. The bearing ID sits on this shaft. Housing is stationary, so the inner race is stationary — it just needs to sit snugly without spinning on the shaft |
| **ISO Designation** | k6 (transition fit for stationary inner race on shaft) |
| **Nominal** | Bearing ID = 25.000mm |
| **CATIA Today** | `Main_bearing_ID = 25mm` — shaft modeled at exact nominal |
| **FDM Target** | Model shaft at **25.10mm** (+0.10mm). FDM shrinks shafts, so printed shaft ≈ 24.9-25.0mm → snug fit in bearing ID |
| **New Parameter** | `main_bearing_shaft_offset = 0.10mm` → shaft = `Main_bearing_ID + main_bearing_shaft_offset` |
| **Post-Processing** | If too tight: sand shaft lightly. If too loose: not recoverable without reprinting |
| **Priority** | **Critical** |

**Shoulder context:** Your skeleton has `main_bearing_shoulder_OD = 34.5mm` and `main_bearing_shoulder_ID = 27.4mm`. The shoulder supports the bearing face axially. The shaft locates it radially.

---

### 1.2 Bottom Main Bearing OD → Carrier Plate Bore

> 6805-2RS outer race (⌀37mm) sits in the bottom carrier plate bore

| Field | Value |
|---|---|
| **Function** | The bottom carrier plate has a bore/shoulder that captures the bottom bearing OD. The carrier rotates, so the outer race rotates with it |
| **ISO Designation** | H7/k6 (transition fit) — conventionally would be P7 press fit for rotating outer race, but we're targeting transition fit for backdrivability (see "FDM Bearing Fit Philosophy") |
| **Nominal** | Bearing OD = 37.000mm |
| **CATIA Today** | Uses `Main_bearing_OD = 37mm` |
| **FDM Target** | Model bore at **37.10mm** (+0.10mm). Same offset as lid bore — targeting the gold standard finger-press feel from coupon v1 |
| **New Parameter** | `carrier_bearing_bore_offset = 0.10mm` → bore = `Main_bearing_OD + carrier_bearing_bore_offset` |
| **Priority** | **Critical** |

**Why transition fit instead of press?** Conventional rule says rotating outer race needs press fit. But FDM surface texture provides enough grip at prototype loads, and backdrivability is the top priority for QDD.

**Creep risk is low:** The lid step constrains the ring gear and carrier axially — the bearing OD can't walk out. Retaining compound is also not a reliable fallback on low-surface-energy filaments (PLA/PETG). If creep does occur, reprint with a reduced bore offset.

---

### 1.3 Top Main Bearing OD → Lid Bore

> 6805-2RS outer race (⌀37mm) seats into lid bore

| Field | Value |
|---|---|
| **Function** | Locate top bearing in the lid. Lid is stationary, so the outer race is stationary — needs a transition fit (snug but assemblable) |
| **ISO Designation** | H7/k6 (transition fit) |
| **Nominal** | Bearing OD = 37.000mm (may change if top bearing size changes in future) |
| **CATIA Today** | Uses `Main_bearing_OD = 37mm` |
| **FDM Target** | Model bore at **37.10mm** (+0.10mm). FDM shrinks holes, so printed bore ≈ 36.9-37.0mm → snug fit |
| **New Parameter** | `lid_bearing_bore_offset = 0.10mm` → bore = `lid_bearing_OD + lid_bearing_bore_offset` |
| **Priority** | **Critical** |

**Note:** The lid prints face-down (open side up per A15), so the bearing bore is built up layer by layer — good for roundness. Uses separate `Lid_bearing_OD` parameter in case the top bearing changes size in the future.

---

### 1.4 Top Main Bearing ID → Carrier Output Shaft

> Carrier output shaft (⌀25mm) fits into top 6805-2RS inner race

| Field | Value |
|---|---|
| **Function** | Carrier rotates — the inner race sits snug on the output shaft |
| **ISO Designation** | k6 (transition fit) — conventionally would be k5 interference for rotating inner race, but targeting transition fit for backdrivability (see "FDM Bearing Fit Philosophy") |
| **Nominal** | Bearing ID = 25.000mm |
| **CATIA Today** | `Main_bearing_ID = 25mm` and `carrier_output_OD = 25.1mm` — offset already baked into param value |
| **FDM Target** | Model shaft at **25.10mm** (+0.10mm). FDM shrinks shafts, so printed shaft ≈ 24.9-25.0mm → snug fit in bearing ID |
| **New Parameter** | `carrier_shaft_offset = 0.10mm` → shaft OD = `Main_bearing_ID + carrier_shaft_offset` |
| **Post-Processing** | If too tight: sand shaft lightly. If too loose: not recoverable without reprinting |
| **Priority** | **Critical** |

**Why transition fit?** Conventionally the rotating inner race needs interference (k5). But FDM surface texture provides grip, and backdrivability is priority. The +0.10mm offset matches the gold standard from coupon v1. If the bearing slips on the shaft, apply loctite or reprint with a slightly larger offset.

---

### 1.5 Planet Bearing OD → Planet Gear Bore

> 685ZZ outer race (⌀14mm) press-fits into planet gear bore

| Field | Value |
|---|---|
| **Function** | Bearing and gear rotate together around the planet pin. Bearing must not spin inside the gear — that would mean the gear isn't transmitting torque through the bearing |
| **ISO Designation** | H7/k6 (transition fit) — conventionally would be P7 press fit for rotating outer race, but targeting transition fit for backdrivability (see "FDM Bearing Fit Philosophy") |
| **Nominal** | Bearing OD = 14.000mm (`carrier_bearing_OD = 14mm`) |
| **CATIA Today** | `planet_bearing_OD = 14mm` — modeled at nominal |
| **FDM Target** | Model bore at **14.15mm** (+0.15mm). Calibration: ⌀14.00 printed 13.75mm (−0.25mm). Expect ~13.90mm printed — ~0.10mm smaller than bearing OD (press fit). Adjust after planet print. |
| **New Parameter** | `planet_bearing_offset = 0.15mm` → bore = `planet_bearing_OD + planet_bearing_offset` = **14.15mm**. Value from Aaron's judgment. Validate with planet print. |
| **Post-Processing** | If bearing won't press in: carefully open bore with round needle file |
| **Priority** | **Critical** — 3 of these (one per planet), all must be consistent |

**Why this is tricky:** The planet gear is the *rotating* part here, while the inner race is clamped to the stationary pin (shoulder screw). So the *outer* race rotates with the gear. Conventionally this means interference fit, but we're targeting transition fit for backdrivability. FDM texture + low loads should prevent creep. The planet gear print will validate this — if the 685ZZ drops in too easily, reduce offset.

**Bearing shoulder context:** `planet_bearing_shoulder_OD = 12.4mm`, `planet_bearing_shoulder_ID = 6.6mm`. These shoulders in the carrier support the bearing faces axially.

**Inner race clearance relief:** The 685ZZ inner race OD must not contact the shoulder step face. If it does, the shoulder screw clamps the inner race against the step, binding the bearing (inner race can't rotate relative to outer race). A relief counterbore is needed on each end of the planet bore, sized to clear the inner race OD.

- **Measured:** 685ZZ inner race OD = **7mm**
- Relief diameter: `planet_inner_race_OD + 0.5mm` = **7.5mm**
- Depth: enough that inner race face doesn't bottom out when bearing is fully seated
- On both ends (one per bearing)
- **Doubles as bearing removal path:** rod inserted through shoulder screw hole from opposite end catches inner race face, drives bearing out
- **Geometry check:** shoulder step OD (12.4mm) > inner race OD (7mm) ✓ — step contacts outer race face and clears inner race

---

### 1.6 Planet Bearing ID → Shoulder Screw (Planet Pin)

> Shoulder screw ⌀5mm through 685ZZ inner race (⌀5mm ID)

| Field | Value |
|---|---|
| **Function** | Inner race is clamped stationary by shoulder screw. Planet + outer race spin around it. Pin must be smooth fit in bearing — standard bearing-on-shaft fit |
| **ISO Designation** | g6 (sliding fit) — bearing ID on shoulder screw shoulder (hardware-to-hardware) |
| **Nominal** | Bearing ID = 5.000mm (`carrier_bearing_ID = 5mm`) |
| **CATIA Today** | `carrier_planet_fastener_diam = 5mm` |
| **FDM Target (bearing interface)** | N/A — shoulder screw is a **purchased machined part**. Bearing ID rides on the screw shoulder. No printed surface involved. |
| **FDM Target (carrier bore)** | The carrier plate has a **printed bore** the shoulder screw passes through to locate the planet axis. This bore IS subject to FDM shrinkage. At ⌀5mm, expect ~0.35mm shrink → bore prints ~4.65mm, shoulder won't pass through. Model at **5.35mm** — screw passes through snugly, minimal axis wobble. |
| **Parameter update** | `carrier_planet_fastener_diam`: 5mm → **5.35mm**. Offset baked in (no separate param — shoulder screw diameter is fixed). |
| **Priority** | **Critical** — slop here = planet axis wobble = gear mesh error |

**Key insight:** The shoulder screw does double duty — it's the planet pin AND the carrier clamshell fastener. The shoulder diameter is what the bearing rides on (hardware-to-hardware, no FDM offset). The **carrier bore** is the printed feature that needs attention.

---

### 1.7 Ring Gear OD → Housing Bore

> Ring gear outer diameter slides into housing cylindrical bore

| Field | Value |
|---|---|
| **Function** | Concentrically locate ring gear. Must be close enough for good concentricity but loose enough to drop in during assembly. Lid presses down on ring gears axially (A2), so radial fit just needs to locate, not retain |
| **ISO Designation** | H7/h6 (locational clearance fit) |
| **Nominal** | Ring gear OD = `ring_pitch_diam + 2*(1.25*gear_module + ring_wall_thickness)` = 75 + 2*(3.125 + 10) = **101.25mm** (`ring_wall_thickness` redefined as minimum solid wall from tooth root — see §5) |
| **CATIA Today** | Housing bore uses `ring_pitch_diam - carrier_ring_clearance` for carrier, but the ring gear housing interface is driven by `ring_pitch_diam + 2*(1.25*gear_module + ring_wall_thickness)`. Need to verify the actual housing bore dimension in CATIA |
| **FDM Target** | **0.3mm diametral clearance** (0.15mm per side). Model housing bore = ring gear OD + 0.3mm. Large diameter = more absolute error, so more clearance needed |
| **New Parameter** | `ring_housing_diam_offset = 0.30mm` |
| **Post-Processing** | Sand ring gear OD if too tight |
| **Priority** | **Critical** — ring gear concentricity directly affects mesh quality |

**Note:** Ring gears are split at mid-height (A4). Both halves must be the same OD and both must fit the same bore. Inconsistency between halves = step in the ring gear teeth.

**Sandwich bolt radial position check:** The sandwich fastener holes pass through the ring gear body at mid-height. After the ring gear OD increases to 101.25mm, verify in CATIA that the bolt circle still falls within the ring gear wall — between the ring root circle radius (~40.6mm) and the ring gear OD radius (~50.6mm). If the bolt circle exits the ring wall, it will break out into air.

---

### 1.8 Sun Gear Bore → Motor Shaft (D-Shaft)

> Sun gear bore fits onto motor D-shaft via press fit

| Field | Value |
|---|---|
| **Function** | Transmit full motor torque to sun gear. D-shaft flat prevents rotation, press fit prevents axial slip |
| **ISO Designation** | H7/p6 (press fit) — but modified for D-shaft geometry |
| **Nominal** | Motor shaft OD = TBD (need to measure). Skeleton has `motor_shaft_clearance_hole = 18mm` for the housing pass-through, but actual shaft is smaller |
| **CATIA Today** | Sun gear bore likely driven by `sun_pitch_diam` (20mm) for the gear geometry, but the bore for the motor shaft is separate. `Gears\Radius.2 = 10mm` (⌀20mm) appears to be the sun pitch circle, and `Gears\Radius.11 = 2.5mm` (⌀5mm) may be the sun gear bore |
| **FDM Target** | Model bore at **nominal shaft diameter** (no offset). D-shaft flat provides anti-rotation. FDM undersizing creates natural press fit |
| **New Parameter** | `motor_shaft_diam = TBD` (measure actual motor shaft with calipers) |
| **Priority** | Important |

**Action needed:** Measure motor shaft diameter with calipers. The D-flat dimension also matters — model the bore to match the shaft profile.

---

### 1.9 Lid Step → Ring Gear / Housing Interface

> Lid has a step that drops down and sits on top of ring gears (A2)

| Field | Value |
|---|---|
| **Function** | The lid step serves two purposes: (1) radially locates lid concentric with housing, (2) presses down on ring gears to hold them axially. This is the primary lid registration feature |
| **ISO Designation** | H7/h6 (locational clearance) for the radial fit between lid step OD and housing bore |
| **Nominal** | Lid step OD ≈ housing bore ID (which is the ring gear bore, ~101.25mm after ring wall redefine — see §1.7, §5) |
| **CATIA Today** | Lid dimensions driven by `housing_lid_thickness = 18.7mm` and related formulas |
| **FDM Target** | **0.2-0.3mm diametral clearance** between lid step and housing bore. Must be loose enough to assemble but tight enough to locate |
| **New Parameter** | `lid_step_clearance = 0.25mm` |
| **Priority** | Important — this is how the lid self-centers |

---

## 2. Axial Fits (Height/Shoulder Interfaces)

### 2.1 Split Ring Gear Height → Housing Cavity

> Combined height of both ring gear halves must fit within housing cavity depth

| Field | Value |
|---|---|
| **Function** | Ring gears sit in housing, lid presses down on them. Need slight clearance so lid seats on housing body (not on ring gears alone — ring gears compress, housing doesn't) |
| **Nominal** | Ring gear total height = `gear_height = 18.6mm` (both halves combined). Housing cavity depth = housing_body_total_height minus base thickness minus bearing pocket minus lid interface |
| **CATIA Today** | `gear_height = 18.6mm`. The cavity depth is implicit from the stack formula |
| **Target** | Ring gear stack should be **0.2-0.5mm shorter** than cavity depth. Lid step applies light axial pressure |
| **New Parameter** | Already partially handled by `carrier_lid_clearance = 4.75mm`, but verify that ring gear height has its own clearance in the stack |
| **Priority** | Important |

**From the height formula (actual CATIA values):**
```
housing_body_total_height = Housing_base_thickness + main_bearing_base_clearance
                          + Main_bearing_height + carrier_plate_bottom_h
                          + gear_height + carrier_plate_thickness
                          + carrier_lid_clearance + housing_lid_thickness
= 5 + 2 + 6.95 + 10.2 + 18.6 + 3.25 + 4.75 + 18.7 = 69.45mm
```
The `carrier_lid_clearance = 4.75mm` provides space between the top of the carrier and the lid. The ring gears occupy the `gear_height = 18.6mm` zone. The lid step drops down onto them — so the lid step depth must be slightly more than the ring gear protrusion above the carrier.

---

### 2.2 Carrier–Planet Axial Stack (Most Critical)

> Shoulder-to-shoulder distance in carrier vs planet + bearing stack

| Field | Value |
|---|---|
| **Function** | Planets must spin freely. Herringbone teeth self-center axially (A9), but the pocket must provide enough room for the planet + bearings without binding |
| **Concern** | Too tight → planets bind, friction kills backdrivability. Too loose → axial rattle (less critical with herringbone since they self-center) |
| **Priority** | **Critical** — directly affects backdrivability |

**Stack analysis (actual CATIA values):**

```
Known dimensions:
  carrier_plate_bottom_h  = 10.2mm   (bottom carrier plate total height)
  carrier_plate_thickness = 3.25mm   (top carrier plate thickness)
  carrier_plate_min_thickness = 2mm  (min solid wall above/below planet pocket)
  carrier_planet_clearance = 1.25mm  (designed gap each side of planet)
  gear_height = 18.6mm               (planet gear height)
  carrier_bearing_h = 5mm            (685ZZ bearing height)

Pocket height = gear_height + 2 × carrier_planet_clearance
             = 18.6 + 2×1.25 = 21.1mm

Planet assembly:
  685ZZ bearings recessed inside through-bore — no protrusion beyond gear faces
  Planet assembly height = 18.6mm (gear only)

Clearance: 21.1 − 18.6 = 2.5mm total (1.25mm each side)
```

**Verdict:** 1.25mm clearance per side is adequate with herringbone self-centering. FDM tolerance ±0.2mm leaves minimum ~1.05mm clearance in worst case. No binding risk.

---

### 2.3 Main Bearing Seating Depth

> Bearing height (6.95mm per skeleton) vs pocket depth

| Field | Value |
|---|---|
| **Function** | Bearing must be fully seated in pocket, supported axially by the shoulder |
| **Nominal** | `Main_bearing_height = 6.95mm` (from skeleton — slightly under the 7mm catalog spec, likely accounting for tolerance) |
| **CATIA Today** | Pocket depth driven by carrier and housing geometry. `main_bearing_base_clearance = 2mm` spaces the bottom bearing above the housing floor |
| **Concern** | The bearing pocket depth is implicit — not a standalone parameter. It's the distance from the bearing shoulder to the housing wall/lid wall |
| **Target** | Pocket depth ≥ `Main_bearing_height` (6.95mm). Bearing should sit flush or slightly proud |
| **New Parameter** | Consider adding `main_bearing_pocket_depth = 7.0mm` as an explicit parameter |
| **Priority** | Important |

---

## 3. Clearance Holes

### 3.1 M3 Fastener Clearance Holes

> Gearbox housing → motor housing. **Measured: M3, 8mm long with stock socket cap.**

| Field | Value |
|---|---|
| **Standard** (ISO 273) | Close fit: ⌀3.4mm / Normal fit: ⌀3.6mm |
| **CATIA Today** | `gearbox_housing_motor_housing_fastener_diam = 3.4mm` — modeled at ISO close-fit clearance, not FDM-corrected |
| **FDM Target** | Model at **~⌀3.8mm**. Calibration coupon: ⌀3.4 printed ~3.0mm (−0.4mm). Need ~3.8mm modeled to get ~3.4mm printed. |
| **Action** | Change `gearbox_housing_motor_housing_fastener_diam` from 3mm to ~3.8mm |
| **Priority** | Standard |

> **⚠ Measurement note:** Small hole measurements (~⌀3–5mm) are approximate — calipers are imprecise on small bores. Revalidate on coupon v2.

### 3.2 M4 Fastener Clearance Holes

> Gearbox housing → motor (ODrive). **Measured: ⌀3.92mm (≈M4), ~6.1mm long.** These are the motor mounting bolts from the ODrive motor.

| Field | Value |
|---|---|
| **Standard** (ISO 273) | Close fit: ⌀4.5mm / Normal fit: ⌀4.8mm |
| **CATIA Today** | `gearbox_housing_motor_fastener_diam = 4.5mm` — modeled at ISO close-fit clearance, not FDM-corrected |
| **FDM Target** | Model at **~⌀4.9mm**. Extrapolated from M3 calibration (~0.35–0.4mm shrink on small holes). |
| **Action** | Change from 4mm to ~4.9mm |
| **Priority** | Standard |

> **⚠ Estimated — not yet validated.** Extrapolated from M3 hole shrinkage. Revalidate on coupon v2.

### 3.3 M5 Sandwich Fastener Clearance Holes

> Housing-lid-ring gear sandwich assembly (4 fasteners)

| Field | Value |
|---|---|
| **Standard** (ISO 273) | Close fit: ⌀5.5mm / Normal fit: ⌀5.8mm |
| **CATIA Today** | `gearbox_housing_sandwich_fastener_diam = 5.5mm` — not yet updated to confirmed value |
| **FDM Target** | Model at **⌀5.35mm**. Tight clearance fit — analogous to shoulder screw bore logic. Aaron confirmed value. |
| **Action** | Change from 5mm to 5.35mm |
| **Priority** | Standard |

> **⚠ Not yet validated.** Revalidate on coupon v2.

### 3.4 Heat-Set Insert Pilot Holes

#### M3 Inserts (carrier, housing)

> M3 heat-set inserts — measured 2026-02-20

| Field | Value |
|---|---|
| **Insert measurements** | OD w/ ribs: 6.03mm, OD smooth body: **4.91mm** |
| **CATIA parameter** | `m3_heatsert_diam` → **5.2mm** |
| **CATIA parameter** | `m3_heatsert_depth` → **6.0mm** |
| **Rationale** | Pilot targets smooth body OD (4.91mm). With ~0.3mm shrink on small holes, model 5.2mm → expect ~4.9mm printed. Ribs melt into plastic during iron insertion. |
| **Priority** | Important |

#### M5 Inserts (output shaft)

> M5 heat-set inserts for output shaft attachment. **Previously documented as M4 — corrected to M5 based on actual hardware.**

| Field | Value |
|---|---|
| **Insert measurements** | OD w/ ribs: 6.97mm, OD smooth body: **5.96mm** |
| **CATIA parameter** | output shaft heatsert diam → **6.3mm** |
| **CATIA parameter** | output shaft heatsert depth → **~6.5mm** |
| **Rationale** | Pilot targets smooth body OD (5.96mm). With estimated shrink, model 6.3mm → expect ~6.0mm printed. |
| **Priority** | Important |

> **⚠ Correction:** Previous versions of this doc listed M4 inserts for the output shaft. Actual hardware is M5. `m5_heatsert_diam = 6.3mm` and `m5_heatsert_depth = 6.5mm` are the active params. `m4_heatsert_diam` and `m4_heatsert_depth` still exist in the skeleton (at 5mm / 6mm) but are **dead params — delete from skeleton**. No M4 inserts exist in this design.

> **⚠ Measurement note:** Insert and small hole measurements are approximate (calipers imprecise on small features). Heatsert fits will be validated when carrier or housing is printed.

**Note on carrier alignment:** The two carrier halves are aligned by the 3 shoulder screws (which double as planet pins). No separate dowel pins or locating features are needed — the shoulder screws passing through the planet bearings constrain angular position of both halves.

---

## 4. Critical Stack-Up Analyses

### 4.1 Full Axial Stack (Housing Assembly)

This is the tolerance chain Aaron flagged as most concerning (A17). The lid, ring gears, carrier, and bearings all stack axially.

```
                    ┌─────────────────────────┐
                    │      Lid (top)           │
                    │  ┌───────────────────┐   │  Main_bearing_height = 6.95mm
                    │  │ Top main bearing   │   │
                    │  │ (6805-2RS)         │   │
                    │  └───────────────────┘   │
                    │     carrier_lid_clearance │  = 4.75mm
                    ├─────────────────────────┤
  carrier_plate_    │  Top carrier plate       │  = 3.25mm
  thickness         ├─────────────────────────┤
                    │                          │
  gear_height       │  Gears + Planets         │  = 18.6mm
                    │  (ring gears fill this)  │
                    │                          │
                    ├─────────────────────────┤
  carrier_plate_    │  Bottom carrier plate     │  = 10.2mm
  bottom_h          │  (includes bearing seat) │
                    ├─────────────────────────┤
                    │  ┌───────────────────┐   │
  Main_bearing_     │  │ Bottom main bearing│   │  = 6.95mm
  height            │  │ (6805-2RS)         │   │
                    │  └───────────────────┘   │
  main_bearing_     │  (clearance to base)     │  = 2mm
  base_clearance    ├─────────────────────────┤
  Housing_base_     │  Housing base            │  = 5mm
  thickness         └─────────────────────────┘

  Total = 5 + 2 + 6.95 + 10.2 + 18.6 + 3.25 + 4.75 + 18.7 = 69.45mm ✓
```

**Where tolerance accumulates:**

| Component | Nominal | FDM Tolerance | Worst Case |
|---|---|---|---|
| Housing base thickness | 5.00mm | ±0.20mm | 4.80–5.20mm |
| Main bearing clearance | 2.00mm | ±0.20mm | 1.80–2.20mm |
| Bottom bearing (purchased) | 6.95mm | ±0.05mm | 6.90–7.00mm |
| Bottom carrier plate | 10.20mm | ±0.20mm | 10.00–10.40mm |
| Gear zone | 18.60mm | ±0.20mm | 18.40–18.80mm |
| Top carrier plate | 3.25mm | ±0.20mm | 3.05–3.45mm |
| Carrier-lid clearance | 4.75mm | — (result) | — |
| Top bearing (purchased) | 6.95mm | ±0.05mm | 6.90–7.00mm |
| Lid (printed) | 18.70mm | ±0.20mm | 18.50–18.90mm |

**Worst-case total range:** 67.45mm to 71.45mm (vs nominal 69.45mm)

**The `carrier_lid_clearance = 4.75mm` is the buffer.** In worst case, printed parts could eat into this clearance by up to ~1.0mm (all tolerances stacking against you), leaving ~3.75mm. Comfortable margin — the lid will seat.

**Verdict:** The 4.75mm `carrier_lid_clearance` provides generous margin. This is the first thing to check if the lid doesn't seat flat, but it's unlikely to be a problem.

---

### 4.2 Radial Concentricity Chain

All gear meshes depend on these features being concentric to Datum B (central axis):

```
Concentricity error budget:

  Housing bore (ring gear location)    ±0.15mm  (FDM bore roundness)
+ Carrier bearing play                 ±0.05mm  (bearing internal clearance)
+ Carrier pin position                 ±0.10mm  (FDM hole position)
+ Ring gear OD to ID concentricity     ±0.10mm  (FDM print accuracy)
─────────────────────────────────────────────
= Worst case total mesh error          ±0.40mm
```

**This is larger than the 0.08mm runout target in 08-gdt-notes.md.** But that target assumed post-processing (reaming). Since Aaron wants as-printed (A14), the realistic target is ±0.2-0.3mm mesh alignment error.

**Is ±0.3mm acceptable?** For a 3D-printed prototype with `module ~2.5` gears (tooth height ~5.6mm), ±0.3mm radial error is ~5% of tooth height. This will cause some non-uniform loading but shouldn't prevent the gears from meshing. Expect slightly noisier operation and faster wear on the high-contact sides.

**Mitigation:** The herringbone teeth help — they self-center axially and are more tolerant of slight radial misalignment than spur gears.

---

### 4.3 Carrier–Planet Pocket Stack

```
Pocket height available = f(carrier geometry)

Planet assembly inside pocket:
  Bearing (685ZZ):     5mm
  Planet gear:        18.6mm  (gear_height)
  Bearing (685ZZ):     5mm
  ─────────────────
  Total:              28.6mm  (if bearings sit outside the gear bore)

  OR if bearings sit inside the gear bore (18.6mm deep bore, 5mm bearing):
  Total:              18.6mm  (bearings recessed inside gear)
```

**This depends on whether the 685ZZ bearings protrude beyond the planet gear faces.** The gear is 18.6mm tall, and the bearing is 5mm wide. If the bore goes all the way through, the bearings sit 6.8mm inside each end — well within the gear body. No protrusion.

**With `carrier_planet_clearance = 1.25mm` on each side:** The pocket is 18.6mm (gear) + 2×1.25mm (clearance) = 21.1mm. The planet assembly is 18.6mm. That's 2.5mm total clearance — adequate with herringbone self-centering.

**Verdict:** No risk of binding. The herringbone self-centering means the planets will find their axial position naturally.

---

## 5. Gear Module & Clearance Fix

**Problem discovered:** Carrier pocket clearances and the ring gear wall thickness are based on pitch diameters, but actual gear teeth extend beyond the pitch circle. This means carrier pockets may be too small and the ring gear wall is thinner than expected.

### The Missing Parameter

```
gear_module = 2.5mm
```

Calculated from: `module = pitch_diam / number_of_teeth`
- Sun: 20mm / 8 teeth = 2.5mm
- Planet: 27.5mm / 11 teeth = 2.5mm
- Ring: 75mm / 30 teeth = 2.5mm

### How Teeth Extend Beyond Pitch Diameter

| Dimension | Formula | Meaning |
|---|---|---|
| **Addendum** (tip above pitch) | `1.0 × gear_module` = 2.5mm | How far tooth tips extend outward |
| **Dedendum** (root below pitch) | `1.25 × gear_module` = 3.125mm | How deep tooth roots cut inward |
| **Tip diameter** (external gear) | `pitch_diam + 2 × gear_module` | Outer edge of tooth tips |
| **Root diameter** (external gear) | `pitch_diam - 2.5 × gear_module` | Bottom of tooth roots |

### Actual Gear Tip Diameters

| Gear | Pitch Diam | Tip Diam | Root Diam |
|---|---|---|---|
| Sun | 20mm | **25mm** | 13.75mm |
| Planet | 27.5mm | **32.5mm** | 21.25mm |
| Ring (internal — teeth point inward) | 75mm | **70mm** (tips inward) | **81.25mm** (roots at OD side) |

### What to Fix in CATIA

**1. Add parameter:** DONE
- `gear_module = 2.5mm`

**2. Fix planet pocket clearance cut: ** DONE
 - **Current:** based on `planet_pitch_diam + clearance` (pocket only 27.5 + clearance)
- **Problem:** actual planet OD is 32.5mm — teeth crash into carrier wall
- **Fix:** change to `planet_pitch_diam + 2 * gear_module + clearance`
- This makes the pocket clear the tooth tips, not just the pitch circle

**3. Fix sun gear passthrough clearance cut:** DONE
- **Current:** based on `sun_pitch_diam + clearance`
- **Problem:** actual sun tip diameter is 25mm, not 20mm
- **Fix:** change to `sun_pitch_diam + 2 * gear_module + clearance`

_**4. Ring gear wall thickness — redefined (2026-02-20): done**_
- `ring_wall_thickness = 10mm` is now defined as the **minimum solid wall from tooth root to ring gear OD**
- The tooth root (dedendum) sits `1.25 × gear_module` = 3.125mm inside the pitch circle, so:
  - Ring gear OD = `ring_pitch_diam + 2*(1.25*gear_module + ring_wall_thickness)` = 75 + 2*(3.125 + 10) = **101.25mm**
- **Correction (was "7.5mm", error):** Previous version said solid wall = `ring_wall_thickness − gear_module` = 7.5mm. That was wrong — it subtracted the addendum (1×module) instead of the dedendum (1.25×module). Actual solid wall under the old definition (pitch to OD) = 10 − 3.125 = **6.875mm**, not 7.5mm.
- Under the new definition, `ring_wall_thickness` IS the solid wall. Parameter value stays 10mm — the meaning changed, and the OD formula updated to match.

### Why This Matters Parametrically

If you ever change `gear_module` (different tooth size), the clearance cuts and wall thickness automatically adjust. Without this parameter, changing tooth size would silently break the carrier pockets.

---

## 6. CATIA Parameter Summary

### New Parameters — Status

| CATIA Param Name | Value in CATIA | Status | Notes |
| --- | --- | --- | --- |
| `gear_module` | 2.5mm | ✅ Done | |
| `main_bearing_shaft_offset` | 0.10mm | ✅ Done | Doc previously called this `housing_bearing_shaft_offset` |
| `planet_bearing_offset` | 0.20mm | ⚠ Needs update → **0.15mm** | Doc calls this `planet_bore_offset`; `planet_bearing_bore` auto-updates |
| `carrier_bearing_bore_offset` | 0.10mm | ✅ Done | |
| `lid_bearing_bore_offset` | 0.10mm | ✅ Done | |
| `lid_bearing_OD` | 37mm | ✅ Done | Doc had capital `Lid_bearing_OD` |
| `carrier_shaft_offset` | 0.10mm | ✅ Done | |
| `ring_housing_diam_offset` | 0.30mm | ✅ Done | |
| `lid_step_clearance` | 0.25mm | ✅ Done | |
| `planet_inner_race_OD` | — | ❌ Not yet added | Value: 7mm (measured). Used for inner race relief counterbore (⌀7.5mm)  |
| NOTE: ISNT THE INNER RACE OD ALREADY A THING? PLANET_BEARING_SHOULDER_ID | | | |

### Existing Parameters to Modify

| Parameter | CATIA Value | Target | Status | Notes |
|---|---|---|---|---|
| `carrier_planet_fastener_diam` | 5.35mm | 5.35mm | ✅ Done | Shoulder screw carrier bore. Offset baked in. ⚠ Validate with carrier print. |
| `gearbox_housing_motor_housing_fastener_diam` | 3.4mm | **3.8mm** | ❌ Pending | M3 clearance hole. Calibration: 3.4mm printed ~3.0mm. |
| `gearbox_housing_motor_fastener_diam` | 4.5mm | **4.9mm** | ❌ Pending | M4 clearance hole. Extrapolated ~0.35–0.4mm shrink. ⚠ Not yet validated. |
| `gearbox_housing_sandwich_fastener_diam` | 5.5mm | **5.35mm** | ❌ Pending | Aaron confirmed value. ⚠ Not yet validated. |
| `m3_heatsert_diam` | 5.2mm | 5.2mm | ✅ Done | M3 insert pilot. Measured body OD = 4.91mm. |
| `m3_heatsert_depth` | 6mm | 6mm | ✅ Done | |
| `m5_heatsert_diam` | 6.3mm | 6.3mm | ✅ Done | Output shaft (M5, not M4). Measured body OD = 5.96mm. |
| `m5_heatsert_depth` | 6.5mm | 6.5mm | ✅ Done | |
| `m4_heatsert_diam` | 5mm | **DELETE** | ⚠ Dead param | No M4 inserts in design. Delete from skeleton. |
| `m4_heatsert_depth` | 6mm | **DELETE** | ⚠ Dead param | No M4 inserts in design. Delete from skeleton. |

> **⚠ Correction (2026-02-20):** Output shaft inserts are **M5, not M4** as previously documented. Old `m4_heatsert_*` parameters are superseded.
>
> **⚠ Note:** Small hole offsets (clearance holes and heatsert pilots) are extrapolated from approximate caliper measurements on coupon v1. Will be validated when carrier/housing parts are printed with these features.

### Formulas to Add

All nominal bearing parameters (`Main_bearing_OD`, `Main_bearing_ID`, etc.) stay untouched — they represent the real bearing spec and are referenced by multiple features. The offset gets applied on the **specific sketch dimension** that controls each mating feature.

**Leave these alone** (they're nominal references, don't add offsets to them):
- `Main_bearing_OD = 37mm`
- `Main_bearing_ID = 25mm`
- `ring_pitch_diam = 75mm`, `ring_wall_thickness = 10mm`

**Note:** `carrier_output_OD = 25.1mm` in CATIA — the offset is baked into the param value directly rather than via formula. Either approach works.

**Formula status:**

| # | Feature | CATIA Formula (Formula.x) | Target Formula | Result | Status |
| - | --- | --- | --- | --- | --- |
| 1 | Housing body bearing shaft | `Formula.61`: `Main_bearing_ID + main_bearing_shaft_offset` | — | 25.10mm | ✅ Done |
| 2 | Carrier plate bearing bore | `Formula.67`: `Main_bearing_OD + carrier_bearing_bore_offset` | — | 37.10mm | ✅ Done |
| 3 | Lid bearing bore | `Formula.62`: `lid_bearing_OD + lid_bearing_bore_offset` | — | 37.10mm | ✅ Done |
| 4 | Carrier output shaft OD | `Formula.59/69`: `Main_bearing_ID + carrier_shaft_offset` | — | 25.10mm | ✅ Done |
| 5 | Ring gear housing bore | `Formula.60`: `ring_pitch_diam + 2*ring_wall_thickness + ring_housing_diam_offset` = **95.3mm** | `ring_pitch_diam + 2*(1.25*gear_module + ring_wall_thickness) + ring_housing_diam_offset` | **101.55mm** | ❌ Pending |
| 6 | Lid step OD | `Formula.66`: `ring_pitch_diam + 2*ring_wall_thickness - lid_step_clearance` = **94.75mm** | `ring_pitch_diam + 2*(1.25*gear_module + ring_wall_thickness) - lid_step_clearance` | **101.00mm** | ❌ Pending |
| 7 | Housing width | `Formula.32`: `ring_pitch_diam + 2*ring_wall_thickness + 2*Housing_min_wall_thickness` = **109mm** | `ring_pitch_diam + 2*(1.25*gear_module + ring_wall_thickness) + 2*Housing_min_wall_thickness` | **115.25mm** | ❌ Pending |

**Note on naming:** Each bearing interface has its own offset parameter (`main_bearing_shaft_offset`, `carrier_bearing_bore_offset`, `lid_bearing_bore_offset`, `carrier_shaft_offset`) rather than one global value. The lid bore references `lid_bearing_OD` instead of `Main_bearing_OD` — if the top bearing changes size in the future, update only `lid_bearing_OD` and the lid bore adjusts independently.

---

## 6. Calibration Print Strategy

All offsets in this document are theoretical — derived from ISO fit intent and general FDM rules, not from our printer. Before printing real gearbox parts, print a calibration coupon to validate the fits with real hardware.

### Test Coupon Design

A rectangular block (~60×50×25mm) with test features modeled at the **actual FDM target dimensions** from this document. Print it, then test-fit real bearings, bolts, and inserts into it. If a fit feels wrong, measure with calipers to quantify how much to adjust.

#### Coupon Layout

```
  TOP VIEW (~60 x 50mm, 25mm tall)
  ┌─────────────────────────────────────────┐
  │                                         │
  │    ┌─────────┐                          │
  │    │ ⌀37.10  │           ○ ~⌀5.3mm     │
  │    │  bore   │                          │
  │    │ w/shoulder           ○ ~⌀3.8mm     │
  │    └─────────┘                          │
  │                                         │
  │        ○ ⌀14mm            ⊙ ⌀25.10     │
  │        bore w/shoulder    post          │
  │                         (on top)        │
  └─────────────────────────────────────────┘
```

- **⌀25.10mm post** — boss extruded ~15mm upward from the top face
- **⌀37.10mm and ⌀14mm bores** — counterbores with shoulder steps to test bearing seating (see cross-section)
- Keep **≥5mm** solid material between features and between features and block edges

**Bearing bore cross-sections:**

```
  ⌀37.10 bore (main bearing seat)       ⌀14 bore (planet bearing seat)

  ┌───┐         ┌───┐                   ┌──┐       ┌──┐
  │   │         │   │                   │  │       │  │
  │   │ ⌀37.10 │   │                   │  │  ⌀14  │  │
  │   │         │   │                   │  │       │  │
  │   │         │   │                   │  │       │  │
  │   ├─────────┤   │ ← shoulder        │  ├───────┤  │ ← shoulder
  │   │ ⌀34.5  │   │   depth ~7mm     │  │ ⌀12.4 │  │   depth ~5mm
  └───┘         └───┘   (bearing ht)    └──┘       └──┘   (bearing ht)

  Shoulder OD sits between bore         Shoulder OD sits between bore
  wall and bearing ID.                  wall and screw.
  Bearing face rests on this ledge.     Bearing face rests on this ledge.
```

#### Feature Table

All dimensions are the **FDM target values** from this tolerance scheme — what we actually plan to model in the gearbox.

| Feature | Model Dim | Source | Type | Depth/Height | Test-Fit With |
| --- | --- | --- | --- | --- | --- |
| Main bearing bore | **⌀37.10mm** | §1.3 lid bore (+0.10 offset) | Counterbore | 18mm deep | 6805-2RS bearing (push OD in) |
| ↳ shoulder step | **⌀34.5mm**  | §1.1 shoulder OD | Inner bore below shoulder | Thru | Bearing should seat flush on ledge |
| Bearing shaft post | **⌀25.10mm** | §1.1/§1.4 (+0.10 offset) | Boss (upward) | 15mm tall | 6805-2RS bearing (slide ID onto post) |
| Planet bearing bore | **⌀14.00mm** | §1.4 (nominal, FDM undersizes) | Counterbore | 20mm deep | 685ZZ bearing (press OD in) |
| ↳ shoulder step | **⌀12.4mm**  | §1.4 shoulder OD | Inner bore below shoulder | Thru | Bearing should seat flush on ledge |
| Heat-set insert pilot | **~⌀5.3mm** | §3.4 (post-calibration) | Through hole | Thru | M3 heat-set insert (body OD 4.96mm) |
| M3 clearance hole | **~⌀3.8mm** | §3.1 (post-calibration) | Through hole | Thru | M3 bolt (should pass through freely)  |

**Why ⌀37.10?** The coupon tests the transition fit. Both the lid bore (§1.3) and carrier bore (§1.2) are now 37.10mm — all bearing interfaces target the same transition fit. The coupon validates both at once.

Shoulder step depths match bearing heights: ~7mm for 6805-2RS, ~5mm for 685ZZ.

#### CATIA Modeling Steps

1. **Pad** a 60×50×25mm block (sketch rectangle on xy-plane → Pad 25mm)
2. **Pocket** the ⌀37.10mm counterbore — sketch ⌀37.10 circle on top face, Pocket 18mm (not thru)
3. **Pocket** the ⌀34.5mm shoulder bore — sketch ⌀34.5 circle concentric in the ⌀37.10 pocket floor, Pocket → Through All
4. **Pocket** the ⌀14.00mm counterbore — sketch ⌀14.00 circle on top face, Pocket 20mm
5. **Pocket** the ⌀12.4mm shoulder bore — sketch ⌀12.4 circle concentric in the ⌀14 pocket floor, Pocket → Through All
6. **Pocket** the ⌀5.00mm and ⌀3.40mm holes — Through All
7. **Pad** the ⌀25.10mm post — sketch ⌀25.10 circle on top face, Pad 15mm upward

#### Print Settings

**Use the exact same settings planned for real gearbox parts:**
- Same printer, same filament (material, brand, color)
- Same layer height, infill %, infill pattern
- Same nozzle and bed temperature
- **Print orientation:** flat 50×50 face on build plate — bores are vertical (best roundness), post grows upward (good cylindricity). This matches how most gearbox bores will print.

If any settings change for the real build, the calibration data may not transfer — reprint the coupon.

### Fit-Test Procedure

Test each feature with the actual hardware. This is the primary validation — does the fit feel right?

| Feature | Model Dim | Test With | Pass Criteria | Result |
|---|---|---|---|---|
| ⌀37.10 bore | 37.10mm | 6805-2RS bearing OD | Snug push fit — seats with firm hand pressure, doesn't fall out | **PASS** — finger press fit, clicks into place |
| ↳ shoulder | ⌀34.5mm | (same bearing) | Bearing sits flush on ledge, no rocking | Measured ~34.45mm |
| ⌀25.10 post | 25.10mm | 6805-2RS bearing ID | Snug slide-on — slight resistance, no slop | Measured 25.01mm — **not fit-tested** (bearing not slid onto post) |
| ↳ shoulder | ⌀27.4mm | (post shoulder ring) | — | Measured 27.3mm |
| ⌀14.00 bore | 14.00mm | 685ZZ bearing OD | Press fit — needs firm push or light tap, stays put | **FAIL** — bearing won't go in (bore too tight) |
| ↳ shoulder | ⌀12.4mm | (same bearing) | Bearing seats flush on ledge | Measured 12.07mm |
| ⌀5.00 hole | 5.00mm | Heat-set insert | Insert threads in with soldering iron, no excessive melt | Printed 4.65mm — too small |
| ⌀3.40 hole | 3.40mm | M3 bolt | Bolt passes through freely, minimal slop | Printed ~3.0mm — too tight |

### Calibration Results (2026-02-19)

#### Measurement Data

| Feature | Modeled | Measured | Deviation | Notes |
|---|---|---|---|---|
| ⌀37.1 bore | 37.10mm | ~37.0mm | **−0.10mm** | Hard to measure, fit feels great |
| ⌀34.5 shoulder | 34.50mm | ~34.45mm | −0.05mm | Hard to measure |
| ⌀25.1 post | 25.10mm | 25.01mm | −0.09mm | Shaft shrinks as expected |
| ⌀27.4 shoulder | 27.40mm | 27.3mm | −0.10mm | |
| ⌀14.0 bore | 14.00mm | 13.75mm | **−0.25mm** | Bearing OD = 14.00mm exact, won't fit |
| ⌀12.4 shoulder | 12.40mm | 12.07mm | **−0.33mm** | |
| ⌀5.0 hole | 5.00mm | 4.65mm | **−0.35mm** | |
| ⌀3.4 hole | 3.40mm | ~3.0mm | **−0.40mm** | M3 clearance hole |

**Trend: smaller features shrink proportionally more.** The ⌀37mm bore lost ~0.3% while the ⌀3.4mm hole lost ~12%.

**Possible contributor: Z-seam alignment.** Printed with random seam, but on small-diameter holes the seam bump takes up a proportionally larger fraction of the circumference. A seam bump that's negligible on a ⌀37mm bore may noticeably tighten a ⌀3.4mm hole. Consider testing "aligned" seam (away from bore interiors) on coupon v2 to isolate this effect.

#### Heat-Set Insert Measurements (corrected 2026-02-20)

Inserts re-measured more carefully:

| Insert | OD w/ ribs | OD smooth body | Pilot hole to model | Depth |
|---|---|---|---|---|
| **M3** | 6.03mm | **4.91mm** | **5.2mm** | 6.0mm |
| **M5** (output shaft) | 6.97mm | **5.96mm** | **6.3mm** | ~6.5mm |

> **Correction:** Output shaft inserts are M5, not M4 as previously documented.

Pilot hole should be sized for the body OD (without ribs). The ribs melt into surrounding plastic during installation.

#### What to Update

**⚠ Measurement Uncertainty:** Small feature measurements (⌀3–5mm holes) are approximate — calipers are imprecise on small bores. Recommended offsets for small holes should be revalidated on coupon v2. The bearing fits (⌀37, ⌀25, ⌀14) are more reliable since hardware fit-testing gives direct pass/fail.

**Working fits (keep current offsets):**
- `lid_bearing_bore_offset = 0.10mm` — ⌀37.10 bore → finger press fit. Perfect for transition fit. **Validated.**
- `main_bearing_shaft_offset = 0.10mm` — ⌀25.10 post → printed 25.01mm. Dimension looks right, but **bearing not test-fitted onto post** — needs fit-test on next build.
- `carrier_shaft_offset = 0.10mm` — same post diameter, same situation. **Needs fit-test.**
- `carrier_bearing_bore_offset = 0.10mm` — changed from 0.00mm (press fit) to 0.10mm (transition fit) per bearing fit philosophy decision. Matches lid bore offset. **Not yet validated — will test when carrier prints.**

**Corrections applied (all done — see §6 for current CATIA status):**

| Parameter | Coupon finding | Applied value |
| --- | --- | --- |
| `planet_bearing_offset` | ⌀14 bore printed 13.75mm (−0.25mm) | **0.15mm** (Aaron's judgment) |
| `m3_heatsert_diam` | Insert body OD = 4.91mm (re-measured) | **5.2mm** |
| M3 clearance hole (`gearbox_housing_motor_housing_fastener_diam`) | Printed ~3.0mm, need ~3.4mm | **3.8mm** target |
| M4 clearance hole (`gearbox_housing_motor_fastener_diam`) | Extrapolated from M3 shrink | **4.9mm** target |
| M5 clearance hole (`gearbox_housing_sandwich_fastener_diam`) | — | **5.35mm** (Aaron confirmed) |
| Output shaft heatsert | Was M4 — corrected to M5, body OD = 5.96mm | **6.3mm** (`m5_heatsert_diam`) |

**Planet bearing shoulder (⌀12.4 → 12.07 printed):** Lost 0.33mm. May need a shoulder offset bump. Retest after planet print.

#### Next Steps (2026-02-20)

1. ~~Update CATIA parameters with new offsets~~ → In progress, see [2026-02-20 log](2026-02-20.md)
2. **Print planet gear** — validates bearing bore offset (+0.20mm, slightly conservative) with a real part
3. Test 685ZZ press fit — goal: match main bearing feel from coupon v1
4. Heatsert fits validated later when carrier/housing is printed (planet has no inserts)

### Python Calibration Calculator (Future)

A simple Python script that takes measured vs modeled dimensions, calculates per-feature offsets, and outputs corrected CATIA parameter values. Good candidate for a learning exercise in `learning/skill-building/`.

---

## Revision History

| Date | Change |
|---|---|
| 2026-02-18 | Initial skeleton created |
| 2026-02-18 | Populated with real CATIA dimensions, FDM values, stack-up analyses from discussion answers |
| 2026-02-19 | Expanded calibration section: detailed coupon layout, CATIA steps, fit-test procedure |
| 2026-02-19 | First calibration print results: main bearing fit good, planet bore needs +0.25mm, small holes need significant offset increase, M3 heatsert larger than assumed |
| 2026-02-20 | Corrected heatsert measurements (M3: 4.91mm body, M5 replaces M4: 5.96mm body). Updated all pilot hole and clearance hole values. Planet gear print queued as next validation step. |
| 2026-02-20 | Bearing fit philosophy change: all interfaces target transition fit (finger press) for backdrivability. `carrier_bearing_bore_offset` 0.00→0.10mm. Departed from conventional rotating-ring = press fit rule — justified by FDM reality and QDD priorities. |
| 2026-02-20 | Ring wall thickness redefined: `ring_wall_thickness` now means minimum solid wall from tooth root to OD (not pitch to OD). Fixed §5 error (7.5mm → 6.875mm under old definition). Ring gear OD updated from 95mm → 101.25mm with new formula `ring_pitch_diam + 2*(1.25*gear_module + ring_wall_thickness)`. Housing bore and lid step formulas updated. |
| 2026-02-20 | Planet bore offset revised 0.20mm → 0.15mm (Aaron's judgment). Inner race clearance relief added to §1.4 — prevents bearing bind, doubles as removal path. Sandwich fastener diam updated 5.8mm → 5.35mm (Aaron confirmed). |
| 2026-02-20 | Synced doc to actual CATIA parameter dump. Updated §4.1 stack (all values), §4.3 pocket analysis, §2.1 gear height. Fixed CATIA param names (`main_bearing_shaft_offset`, `planet_bearing_offset`, `lid_bearing_OD`). Formula table restructured with done/pending status. Dead `m4_heatsert_*` params flagged for deletion. |

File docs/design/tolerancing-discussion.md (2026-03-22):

# Tolerancing Discussion — Questions for Aaron

Fill in answers below each question. Short answers are fine. Sketches/screenshots welcome if easier.

---

## Assembly Understanding

**Q1: Housing body shape**
Is the housing a cylinder/tube shape, or more of a cup (closed bottom, open top)? Does the motor mount to the bottom of the housing?

**A1:** So the gearbox assembly right now just will sit on top of the motor and the shaft goes through the housing, um, into kind of connects to the sun gear. here. I don't really understand the intent of the question, so I don't know how to answer it well, but it's basically like just a body with a lid kind of thing. I don't know.

**Q2: Lid attachment**
Does the lid sit on top of the housing body? Is there a step/rabbet (like a lip) where the lid registers into the housing, or does it just sit flat on top and the bolts locate it?

**A2:** Yeah, there is like a step. The step basically goes down and sits on top of the ring gears to kind of put pressure on them.

**Q3: Ring gear to housing interface**
You said the housing locates the ring gears concentrically (slide fit). Is there a cylindrical bore in the housing where the ring gear OD slides into? And the ring gears just drop in from the top before the lid goes on?

**A3:**  Yeah, the housing has like a cylindrical bore where the ring gears kind of slide into.

**Q4: Ring gear split plane**
The two ring gear halves — are they split at mid-height (each half has half the gear teeth), or is it a full-height gear + a spacer/adapter ring?

**A4:** Yeah, it just split in half at the middle.

**Q5: Carrier clamshell assembly**
The two carrier halves are held together by shoulder screws that pass through the planet bearings. So the shoulder screw acts as both the planet pin AND the carrier fastener? Is the shoulder of the screw what the bearing inner race sits on?

**A5:** Yes. It acts as the fastener and the pin.

**Q6: Carrier to main bearing interface**
How does the carrier connect to the main bearings (6805-2RS)? Is there a cylindrical boss on each carrier half that sits inside the bearing ID (25mm)? Or does one carrier half have the full shaft that passes through both bearings?

**A6:** So right now, the bottom of the housing has like a lip for the inner diameter of the bearing to kind of sit on. And it's constrained consensually by the bottom housing body. and then the outer diameter of the bearing sits on another kind of shoulder of the bottom of the carrier it's kind of like if we're installing it first you put the the bottom main bearing you put it onto the body and then from there the top of the carrier or the bottom half of the carrier you just push down onto the bearing and there's a there's a lip there that catches it if that makes sense

**Q7: Motor shaft to sun gear**
How is the sun gear attached to the motor shaft? Press fit? Set screw? D-shaft? Key? What's the motor shaft diameter?

**A7:** So right now we just have a press fit. The motor shaft is just like a circle with a flat part in it, so I think we're just going to do press fit for now for the prototype.

---

## Specific Interfaces

**Q8: What prevents the main bearings from moving axially?**
Are there shoulders/snap rings/retaining features in the housing bores that keep the bearings seated? Or are they just pressed in and friction holds them?

**A8:** So the whole assembly is kind of constrained actually by the lid. So what prevents the whole assembly from moving down, so the ring gears are sitting on the body of the housing and then the carrier is kind of sitting on that bottom main bearing which is sitting up on the the housing body, the lip, the bottom one, if that makes sense. And then what prevents it from moving up is the lid has its own bearing and lip that goes on to another lip of the top part of the carrier. I can add an image if it helps, but I don't know how good your image recognition is.

**Q9: Planet axial play**
After the carrier is assembled with shoulder screws through the planet bearings — what controls how much axial play the planets have? Is there a gap between the carrier shoulders and the bearing faces? Is this gap currently defined by a parameter?

**A9:** So, the planets are herringbone so they should be self-centering but they are floating.

**Q10: Are there any seals or O-rings?**
(Probably not for a prototype, but just confirming)

**A10:** No, there is not. This is not going to be a fluid bath design or anything. It's just going to be something like grease, some kind of grease in there. Silicone grease or something but no seals.

---

## Parameters & CATIA

**Q11: Key dimension parameters**
List (or paste) the parameter names and values for these critical dims. If you can't export, just type the key ones:
- Main bearing bore diameter (housing)
- Main bearing ID (carrier shaft OD)
- Planet bearing bore (in planet gear)
- Planet bearing pin diameter (carrier)
- Ring gear OD (fits into housing)
- Ring gear housing bore ID
- Sun gear bore ID
- Motor shaft OD
- Any clearance parameters you've already defined

**A11:** Root: Skeleton A.1

=== Skeleton A.1 ===
  PARAM: Skeleton A.1\PartBody\datum_point (offset from motor)\X = 0mm
  PARAM: Skeleton A.1\PartBody\datum_point (offset from motor)\Y = 0mm
  PARAM: Skeleton A.1\PartBody\datum_point (offset from motor)\Z = 0mm
  PARAM: Skeleton A.1\PartBody\Housing_inside_base\Offset = 5mm
  PARAM: Skeleton A.1\PartBody\Gear_midplane\Offset = 22.45mm
  PARAM: Skeleton A.1\PartBody\top_motor_shaft_plane\Offset = 30mm
  PARAM: Skeleton A.1\PartBody\planet_bearings\Radius.1\Radius = 10mm
  PARAM: Skeleton A.1\PartBody\planet_bearings\Radius.1\Diameter = 20mm
  PARAM: Skeleton A.1\PartBody\planet_bearings\Radius.8\Radius = 2.5mm
  PARAM: Skeleton A.1\PartBody\planet_bearings\Radius.8\Diameter = 5mm
  PARAM: Skeleton A.1\PartBody\planet_bearings\Radius.9\Radius = 7mm
  PARAM: Skeleton A.1\PartBody\planet_bearings\Radius.9\Diameter = 14mm
  PARAM: Skeleton A.1\PartBody\planet_bearings\Length.15\Length = 13.75mm
  PARAM: Skeleton A.1\PartBody\point_abs_datum\X = 0mm
  PARAM: Skeleton A.1\PartBody\point_abs_datum\Y = 0mm
  PARAM: Skeleton A.1\PartBody\point_abs_datum\Z = 0mm
  PARAM: Skeleton A.1\PartBody\PUB_z_axis\X = 0
  PARAM: Skeleton A.1\PartBody\PUB_z_axis\Y = 0
  PARAM: Skeleton A.1\PartBody\PUB_z_axis\Z = 1
  PARAM: Skeleton A.1\PartBody\PUB_z_axis\Start = 0mm
  PARAM: Skeleton A.1\PartBody\PUB_z_axis\End = 150mm
  PARAM: Skeleton A.1\PartBody\Gears\Radius.1\Radius = 37.5mm
  PARAM: Skeleton A.1\PartBody\Gears\Radius.1\Diameter = 75mm
  PARAM: Skeleton A.1\PartBody\Gears\Radius.2\Radius = 10mm
  PARAM: Skeleton A.1\PartBody\Gears\Radius.2\Diameter = 20mm
  PARAM: Skeleton A.1\PartBody\Gears\Radius.9\Radius = 13.75mm
  PARAM: Skeleton A.1\PartBody\Gears\Radius.9\Diameter = 27.5mm
  PARAM: Skeleton A.1\PartBody\Gears\Radius.11\Radius = 2.5mm
  PARAM: Skeleton A.1\PartBody\Gears\Radius.11\Diameter = 5mm
  PARAM: Skeleton A.1\PartBody\Gears\Radius.12\Radius = 7mm
  PARAM: Skeleton A.1\PartBody\Gears\Radius.12\Diameter = 14mm
  PARAM: Skeleton A.1\PartBody\main_bearing\Radius.1\Radius = 12.5mm
  PARAM: Skeleton A.1\PartBody\main_bearing\Radius.1\Diameter = 25mm
  PARAM: Skeleton A.1\PartBody\main_bearing\Radius.2\Radius = 18.5mm
  PARAM: Skeleton A.1\PartBody\main_bearing\Radius.2\Diameter = 37mm
  PARAM: Skeleton A.1\PartBody\main_bearing\Radius.3\Radius = 10mm
  PARAM: Skeleton A.1\PartBody\main_bearing\Radius.3\Diameter = 20mm
  PARAM: Skeleton A.1\PartBody\Carrier\Radius.3\Radius = 35mm
  PARAM: Skeleton A.1\PartBody\Carrier\Radius.3\Diameter = 70mm
  PARAM: Skeleton A.1\PartBody\Carrier\Radius.5\Radius = 23.75mm
  PARAM: Skeleton A.1\PartBody\Carrier\Radius.5\Diameter = 47.5mm
  PARAM: Skeleton A.1\PartBody\carrier_bottom\Offset = 1.5mm
  PARAM: Skeleton A.1\PartBody\carrier_top\Offset = 14mm
  PARAM: Skeleton A.1\PartBody\carrier_min_thickness_top\Offset = 2mm
  PARAM: Skeleton A.1\PartBody\carrier_min_thickness_bottom\Offset = 8.95mm
  PARAM: Skeleton A.1\PartBody\Point.2\H = 0mm
  PARAM: Skeleton A.1\PartBody\Point.2\V = 0mm
  PARAM: Skeleton A.1\PartBody\Point.2\X = 1
  PARAM: Skeleton A.1\PartBody\Point.2\Y = -3.622271632e-071
  PARAM: Skeleton A.1\PartBody\Point.2\Z = -1.504632769e-036
  PARAM: Skeleton A.1\PartBody\gear_top\Offset = 10mm
  PARAM: Skeleton A.1\PartBody\housing_body_top\Offset = 66.35mm
  PARAM: Skeleton A.1\PartBody\Point.5\Length = 23.75mm
  PARAM: Skeleton A.1\PartBody\planet_center_datum_axis\Start = 0mm
  PARAM: Skeleton A.1\PartBody\planet_center_datum_axis\End = 150mm
  PARAM: Skeleton A.1\PartBody\housing_base_mounting_layout\Length.18\Length = 44mm
  PARAM: Skeleton A.1\PartBody\housing_base_mounting_layout\Length.19\Length = 76mm
  PARAM: Skeleton A.1\PartBody\housing_base_mounting_layout\Length.20\Length = 46mm
  PARAM: Skeleton A.1\PartBody\housing_base_mounting_layout\Radius.39\Radius = 2mm
  PARAM: Skeleton A.1\PartBody\housing_base_mounting_layout\Radius.39\Diameter = 4mm
  PARAM: Skeleton A.1\PartBody\housing_base_mounting_layout\Radius.43\Radius = 1.5mm
  PARAM: Skeleton A.1\PartBody\housing_base_mounting_layout\Radius.43\Diameter = 3mm
  PARAM: Skeleton A.1\PartBody\gearbox_assembly_sandwich_fastener_distn\Radius.3\Radius = 42.5mm
  PARAM: Skeleton A.1\PartBody\gearbox_assembly_sandwich_fastener_distn\Radius.3\Diameter = 85mm
  PARAM: Skeleton A.1\PartBody\gearbox_assembly_sandwich_fastener_distn\Radius.6\Radius = 2.5mm
  PARAM: Skeleton A.1\PartBody\gearbox_assembly_sandwich_fastener_distn\Radius.6\Diameter = 5mm
  PARAM: Housing_base_thickness = 5mm
  PARAM: Housing_min_wall_thickness = 7mm
  PARAM: Main_bearing_ID = 25mm
  PARAM: Main_bearing_OD = 37mm
  PARAM: Main_bearing_height = 6.95mm
  PARAM: sun_pitch_diam = 20mm
  PARAM: planet_pitch_diam = 27.5mm
  PARAM: ring_pitch_diam = 75mm
  PARAM: carrier_bearing_ID = 5mm
  PARAM: carrier_bearing_OD = 14mm
  PARAM: carrier_bearing_h = 5mm
  PARAM: number_of_planets = 3
  PARAM: main_bearing_base_clearance = 1.5mm
  PARAM: carrier_plate_bottom_h = 10.95mm
  PARAM: gear_height = 20mm
  PARAM: ring_wall_thickness = 10mm
  PARAM: carrier_ring_clearance = 5mm
  PARAM: carrier_plate_thickness = 4mm
  PARAM: planet_mid_path = 23.75mm
  PARAM: planet_spacing = 120deg
  PARAM: carrier_planet_clearance = 2mm
  PARAM: carrier_diam = 70mm
  PARAM: housing_width = 109mm
  PARAM: housing_body_total_height = 66.35mm
  PARAM: carrier_lid_clearance = 2mm
  PARAM: motor_shaft_clearance_hole = 18mm
  PARAM: main_bearing_shoulder_ID = 27.4mm
  PARAM: housing_lid_thickness = 15.95mm
  PARAM: main_bearing_shoulder_OD = 34.5mm
  PARAM: carrier_output_OD = 25mm
  PARAM: carrier_output_lid_stickout = 1.5mm
  PARAM: carrier_output_shaft_length = 17.45mm
  PARAM: housing_lid_min_thickness = 7mm
  PARAM: carrier_base_clearance = 3mm
  PARAM: planet_bearing_OD = 14mm
  PARAM: planet_bearing_ID = 5mm
  PARAM: planet_bearing_h = 5mm
  PARAM: carrier_plate_min_thickness = 2mm
  PARAM: planet_bearing_shoulder_ID = 6.6mm
  PARAM: planet_bearing_shoulder_OD = 12.4mm
  PARAM: gearbox_housing_motor_fastener_diam = 4mm
  PARAM: gearbox_housing_motor_housing_fastener_diam = 3mm
  PARAM: gearbox_housing_sandwich_fastener_diam = 5mm
  PARAM: number_of_sandwich_fasteners = 4
  PARAM: output_shaft_heatsert_diam = 5.84mm
  PARAM: output_shaft_heatsert_depth = 4.7mm
  PARAM: carrier_heatsert_diam = 0mm
  PARAM: carrier_heatsert_depth = 0mm
  PARAM: carrier_planet_fastener_diam = 5mm
  PARAM: m4_heatsert_diam = 5.84mm
  PARAM: m4_heatsert_depth = 4.7mm
  PARAM: Skeleton A.1\Length.8 = 0mm
  PARAM: Skeleton A.1\Length.9 = 0mm
  PARAM: Skeleton A.1\ABS_origin_axis\Origin\X = 0mm
  PARAM: Skeleton A.1\ABS_origin_axis\Origin\Y = 0mm
  PARAM: Skeleton A.1\ABS_origin_axis\Origin\Z = 0mm
  PARAM: Skeleton A.1\ABS_origin_axis\XAxis\X = 1
  PARAM: Skeleton A.1\ABS_origin_axis\XAxis\Y = 0
  PARAM: Skeleton A.1\ABS_origin_axis\XAxis\Z = 0
  PARAM: Skeleton A.1\ABS_origin_axis\YAxis\X = 0
  PARAM: Skeleton A.1\ABS_origin_axis\YAxis\Y = 1
  PARAM: Skeleton A.1\ABS_origin_axis\YAxis\Z = 0
  PARAM: Skeleton A.1\ABS_origin_axis\ZAxis\X = 0
  PARAM: Skeleton A.1\ABS_origin_axis\ZAxis\Y = 0
  PARAM: Skeleton A.1\ABS_origin_axis\ZAxis\Z = 1
  PARAM: Skeleton A.1\datum_axis (mounting height)\Origin\X = 0mm
  PARAM: Skeleton A.1\datum_axis (mounting height)\Origin\Y = 0mm
  PARAM: Skeleton A.1\datum_axis (mounting height)\Origin\Z = 0mm
  PARAM: Skeleton A.1\datum_axis (mounting height)\XAxis\X = 1
  PARAM: Skeleton A.1\datum_axis (mounting height)\XAxis\Y = 0
  PARAM: Skeleton A.1\datum_axis (mounting height)\XAxis\Z = 0
  PARAM: Skeleton A.1\datum_axis (mounting height)\YAxis\X = 0
  PARAM: Skeleton A.1\datum_axis (mounting height)\YAxis\Y = 1
  PARAM: Skeleton A.1\datum_axis (mounting height)\YAxis\Z = 0
  PARAM: Skeleton A.1\datum_axis (mounting height)\ZAxis\X = 0
  PARAM: Skeleton A.1\datum_axis (mounting height)\ZAxis\Y = 0
  PARAM: Skeleton A.1\datum_axis (mounting height)\ZAxis\Z = 1

  REL [Formula.2]: Housing_base_thickness
  REL [Formula.3]: clearance
  REL [Formula.4]: gear_height/2 + carrier_plate_bottom_h + main_bearing_base_clearance
  REL [Formula.6]: ring_pitch_diam 
  REL [Formula.7]: sun_pitch_diam 
  REL [Formula.8]: (ring_pitch_diam -sun_pitch_diam)/2
  REL [Formula.9]: planet_pitch_diam 
  REL [Formula.13]: Main_bearing_ID 
  REL [Formula.14]: Main_bearing_OD 
  REL [Formula.15]: ring_pitch_diam-carrier_ring_clearance
  REL [Formula.17]: (sun_pitch_diam+planet_pitch_diam)/2
  REL [Formula.18]: planet_mid_path
  REL [Formula.20]: 360deg/number_of_planets
  REL [Formula.29]: main_bearing_base_clearance
  REL [Formula.30]: gear_height/2 + carrier_plate_thickness
  REL [Formula.31]: ring_pitch_diam - carrier_ring_clearance
  REL [Formula.32]: ring_pitch_diam+2*ring_wall_thickness+2*Housing_min_wall_thickness
  REL [Formula.33]: Housing_base_thickness+main_bearing_base_clearance+Main_bearing_height+carrier_plate_bottom_h+gear_height+carrier_plate_thickness +carrier_lid_clearance + housing_lid_thickness
  REL [Formula.34]: gear_height/2
  REL [Formula.35]: housing_body_total_height
  REL [Formula.36]: housing_lid_thickness+carrier_output_lid_stickout
  REL [Formula.37]: housing_lid_min_thickness+Main_bearing_height+carrier_lid_clearance
  REL [Formula.38]: carrier_plate_min_thickness + carrier_planet_clearance
  REL [Formula.39]: carrier_plate_thickness+Main_bearing_height
  REL [Formula.40]: sun_pitch_diam 
  REL [Formula.44]: sun_pitch_diam 
  REL [Formula.46]: planet_bearing_ID 
  REL [Formula.47]: planet_bearing_OD 
  REL [Formula.48]: planet_pitch_diam/2
  REL [Formula.49]: carrier_plate_min_thickness 
  REL [Formula.50]: carrier_plate_bottom_h-carrier_planet_clearance
  REL [Formula.52]: planet_mid_path 
  REL [Formula.53]: gearbox_housing_motor_fastener_diam
  REL [Formula.54]: gearbox_housing_motor_housing_fastener_diam
  REL [Formula.55]: ring_pitch_diam + ring_wall_thickness
  REL [Formula.56]: gearbox_housing_sandwich_fastener_diam
  REL [Formula.57]: m4_heatsert_diam
  REL [Formula.58]: m4_heatsert_depth

**Q12: Do you have separate parameters for "nominal" vs "modeled" dimensions?**
e.g., do you have `main_bearing_od = 37` and then the bore is set to `main_bearing_od + some_clearance`? Or is the bore just set to `37` directly?

**A12:** No, there is no nominal or modeled. It's just I did it all as the same. So that's where some of the complexity comes in. Yeah. So for example, for the main bearing, it would just be the main underscore bearing underscore OD equals 37 as my dimension I use to model things.

---

## Manufacturing & Practical

**Q13: Bambu P1S — have you done any test prints for fit?**
Have you printed any test pieces to check how accurate your printer is for bores, pins, and mating surfaces? If so, what offsets did you find?

**A13:** No, we haven't done any testing yet. But we likely will before printing this. But it's parametric, so once we learn the fitment, then we can adjust accordingly. As long as there's some way to translate the test info to the parametric values in the assembly. like maybe a calculator or something we could do in python that's like oh you print a 20 millimeter cube it's this off therefore your bearing from it should be this or like it could be like I don't know we could discuss this again

**Q14: Post-processing plan**
Which features do you plan to post-process (ream, sand, drill)? Or are you hoping most things work as-printed?

**A14:** I'm hoping everything works as printed, as simple as possible. Yeah.

**Q15: Print orientation**
Are you planning to print the housing upright (open top up)? Gears flat? What about the carrier halves?

**A15:** Yeah, the design will need some supports. It's not perfect. It is a prototype. First time learning this CAD software so just trying to get this done as soon as possible. Yeah, open top up. Gear is flat. Carrier halves. Probably just printed beside each other.

---
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

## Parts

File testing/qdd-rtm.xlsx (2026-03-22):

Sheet: Dashboard
QDD Actuator — Project Dashboard
Requirements Summary
Total Requirements | 13
Verified | 0
Failed | 2
Partial | 1
Pending Review | 2
Not Verified | 8
% Verified | 0.0%
Test Campaign Summary
Total Tests | 19
Complete | 5
In Progress | 0
Not Started | 14
Pass | 1
Fail | 2
% Complete | 26.3%
Test Level Breakdown | Total | Complete
Component | 5 | 1
Interface | 4 | 4
Subsystem | 0 | 0
System | 10 | 0
% Complete by Level | 0.0% | 26.3%
Traceability Coverage
Covered (Primary Test) | 2
Partial (Secondary Only) | 4
Via Inspection/Demo/Analysis | 5
Gap (No Coverage) | 2
Gap Req IDs | R-07, R-08
Unknowns Register
Total Unknowns | 10
Resolved | 1
Open (excl. Merged) | 8
% Resolved | 11.1%

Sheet: Requirements
Req ID | Requirement | Description | Target Value | Type | Priority Rank | Verification Method | Verification Level | Status | Verified By | Notes
R-01 | Backlash | Angular backlash at output shaft | ≤ 0.5° | Hard | 1 | Test | System | Partial | T-012 | Primary QDD metric. Measured with dial indicator.
R-02 | Cost | Total BOM cost under budget | < $120 CAD | Hard | 2 | Inspection | Component | Pending Review | BOM inspection | Sum of purchased + printed parts cost
R-03 | DFM/DFA | All off-the-shelf + 3D printed parts; assemblable without complex tools | Off-the-shelf + FDM, no special tools | Hard | 3 | Inspection | Component | Pending Review | Design review | Assembly with basic hex keys only
R-04 | Backdrivability | Friction torque with motor disconnected | < 1 Nm friction torque | Hard | 4 | Test | System | Failed | T-013, T-008, T-006 | Changed from vague 'backdriveable under human impulse' to measurable spec (Mar 11). Industry standard for QDD.
R-05 | Durability | Should not break itself in under 1 minute | No self-destruction in < 1 min | Hard | 5 | Test | System | Not Verified |  | Phase 5 only. Combination of software + hardware limits.
R-06 | Peak Torque | Peak torque output at gearbox output shaft | ≥ 16 Nm | Hard | 6 | Test | System | Not Verified |  | Phase 5 only. Needs load cell or heavy weights.
R-07 | Continuous Torque | Sustained torque output capacity | ≥ 12 Nm | Hard | 7 | Test | System | Not Verified |  | Phase 5 only. Needs thermal steady-state test.
R-08 | Thermal Performance | Housing should not overheat under sustained use | No melting in < 5 min | Hard | 8 | Test | System | Not Verified |  | Phase 5 only. PLA Tg ~60°C. Health monitoring tracks informally.
R-09 | Efficiency | Power transmission efficiency through gearbox | > 90% | Soft | 9 | Test | System | Failed | T-006 (related) | Phase 5 only. T-006 measures friction but not output power directly.
R-10 | Weight | Total assembly mass | < 2 kg | Soft | 10 | Inspection | Component | Not Verified |  | Trivial — kitchen scale measurement. Add as 1-min check in Phase 1.
R-11 | Speed | Maximum continuous output RPM | ≥ 600 RPM continuous | Soft | 11 | Test | System | Not Verified | T-016 (related) | T-016 measures bandwidth, not sustained max RPM. No direct 600 RPM test yet.
R-12 | Integratable | Support either shaft or bolted plate outputs | Shafts or bolted plates | Soft | 12 | Demonstration | Subsystem | Not Verified |  | Design review / demo of integration options.
R-13 | Torque Density (volume) | High torque output relative to actuator volume | No specific target set | Soft | 13 | Analysis | Component | Not Verified |  | Compare to commercial QDDs (e.g., CubeMars AK70-10).

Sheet: Traceability Matrix
 |  | Ph0 | Ph0 | Ph0 | Ph0 | Ph1 | Ph1 | Ph2 | Ph2 | Ph2 | Ph3 | Ph3 | Ph4 | Ph4 | Ph4 | 00A | 00A | 00A | 00A | 00A
 | Test Level | Comp | Comp | Comp | Comp | Sys | Sys | Sys | Sys | Sys | Sys | Sys | Sys | Sys | Sys | Intf | Intf | Comp | Intf | Intf
Req ID | Requirement | T-009 Motor Kt | T-010 Motor Cogging | T-011 Motor Friction | T-014 Motor Step Resp | T-012 Backlash | T-013 Hand Backdrive | T-006 Friction Model | T-007 Step Response | T-008 Backdrive Torque | T-015 Plant ID | T-016 Bode Plot | T-017 Virtual Spring | T-018 Spring-Damper | T-019 Variable Imped | T-001 Root Cause Mesh | T-002 Lid Drag | T-003 Shoulder Deform | T-004 Carrier Index | T-005 Bolt vs Drag | Coverage
R-01 | Backlash |  |  |  |  | P |  |  |  |  |  |  |  |  |  | S |  |  | S |  | Covered
R-02 | Cost |  |  |  |  |  |  |  |  |  |  |  |  |  |  |  |  |  |  |  | Via Inspection
R-03 | DFM/DFA |  |  |  |  |  |  |  |  |  |  |  |  |  |  |  |  |  |  |  | Via Inspection
R-04 | Backdrivability |  |  |  |  |  | P | P |  | P |  |  |  |  |  | S | S |  |  | S | Covered
R-05 | Durability |  |  |  |  |  |  |  |  |  |  |  |  |  |  |  |  | S |  | S | Partial
R-06 | Peak Torque |  |  |  |  |  |  |  |  |  |  |  |  |  |  |  |  | S |  | S | Partial
R-07 | Continuous Torque |  |  |  |  |  |  |  |  |  |  |  |  |  |  |  |  |  |  |  | Gap
R-08 | Thermal Performance |  |  |  |  |  |  |  |  |  |  |  |  |  |  |  |  |  |  |  | Gap
R-09 | Efficiency |  |  | S |  |  |  | S |  |  |  |  |  |  |  |  |  |  |  |  | Partial
R-10 | Weight |  |  |  |  |  |  |  |  |  |  |  |  |  |  |  |  |  |  |  | Via Inspection
R-11 | Speed |  |  |  |  |  |  |  |  |  |  | S |  |  |  |  |  |  |  |  | Partial
R-12 | Integratable |  |  |  |  |  |  |  |  |  |  |  |  |  |  |  |  |  |  |  | Via Demonstration
R-13 | Torque Density (volume) |  |  |  |  |  |  |  |  |  |  |  |  |  |  |  |  |  |  |  | Via Analysis
 | Traces To → | Char. | Char. | R-09 | Char. | R-01 | R-04 | R-04, R-09 | Char. | R-04 | Char. | R-11 | Char. | Char. | Char. | R-01, R-04 | R-04 | R-05, R-06 | R-01 | R-04, R-05, R-06
Legend
P | Primary verification test
S | Secondary / supporting test
 | No direct link
Char. | Characterization test (no specific req)
Level Colors
Comp | Component-level test
Intf | Interface-level test
Sys | System-level test

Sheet: Test Log
Test ID | Test Name | Phase | Test Level | Traces To | Procedure Reference | Prerequisites | Status | Date Executed | Result | Acceptance Criteria | Pass/Fail | Notes / Actions | Trace Valid?
T-001 | Root cause analysis — tight gear meshing | Rev 00A | Interface | R-01, R-04 | test-tracker.md T-001 | Part dimensions | Complete | 2026-03-13 | Herringbone alignment error identified | Dimensions within printer tolerance | Partial | Root cause: herringbone misalignment. Action: spur gears for Rev 00B. Dimensional measurements still pending. | ✓
T-002 | Lid drag — over-constraint on carrier | Rev 00A | Interface | R-04, R-09 | test-tracker.md T-002 | None | Complete | 2026-03-13 | Root cause identified — tolerance stackup | Lid does not add parasitic drag | Fail | Lid double-duty causes stackup. Design change: decouple ring gear clamping from carrier constraint. | ✓
T-003 | Carrier bearing shoulder deformation | Rev 00A | Component | R-05, R-06 | test-tracker.md T-003 | None | Complete | 2026-03-13 | Print quality issue on top carrier shoulders | Shoulder change < 0.1 mm, no cracking | Inconclusive | Bottom shoulders good. Top shoulders have print artifacts (orientation trade-off). No dimensional measurement yet. | ✓
T-004 | Carrier half indexing — clocking under load | Rev 00A | Interface | R-01 | test-tracker.md T-004 | T-003 | Complete | 2026-03-13 | ~0.5 mm play exists but no operational driving force | No visible relative motion under hand torsion | Pass | Load path analysis: both halves driven by same pins. Clocking not a realistic failure mode. | ✓
T-005 | Carrier bolt torque vs planet resistance | Rev 00A | Interface | R-04, R-05 | test-tracker.md T-005 | None | Complete | 2026-03-13 | Narrow window between carrier play and planet binding | Planets spin freely across bolt torque range | Fail | Shoulders sensitive to clamping force. 1.1 Nm → drag. Backed off → free. Rev 00B shoulder redesign needed. | ✓
T-006 | Friction characterization — Coulomb + viscous | Phase 2 | System | R-04, R-09 | test-campaign-rev00b.md Phase 2 | Motor + encoder + ODrive, gearbox assembled | Not Started |  |  | Reflected friction torque < 1 Nm; linear friction model |  | Motor torque current at constant velocities. Subtract T-011 baseline for gearbox-only friction. | ✓
T-007 | Step response — system dynamics | Phase 2 | System | — | test-campaign-rev00b.md Phase 2 | Motor + encoder + ODrive, gearbox assembled | Not Started |  |  | System settles, overshoot < 10%, SSE < 0.5° |  | Characterization test. Compare to T-014 motor-only baseline. | N/A
T-008 | Backdriving torque — passive resistance | Phase 2 | System | R-04 | test-campaign-rev00b.md Phase 2 | Motor + encoder + ODrive, gearbox assembled | Not Started |  |  | Backdriving torque < 1 Nm at output |  | Quantitative version of T-013. Motor in idle, turn output by hand. | ✓
T-009 | Motor Kt verification (baseline) | Phase 0 | Component | — | test-campaign-rev00b.md Phase 0 | ODrive + motor + encoder configured | Not Started |  |  | No-load Iq < 1A at 2 rev/s |  | Baseline sanity check. Every downstream torque calc depends on Kt. | N/A
T-010 | Motor cogging & friction profile | Phase 0 | Component | — | test-campaign-rev00b.md Phase 0 | T-009 pass | Not Started |  |  | Periodic cogging, roughly symmetric CW/CCW |  | Motor-only baseline. Needed to isolate gearbox effects in T-006. | N/A
T-011 | Motor friction vs speed — no load | Phase 0 | Component | — | test-campaign-rev00b.md Phase 0 | T-009 pass | Not Started |  |  | Roughly linear friction vs speed |  | Motor-only Coulomb + viscous model. Baseline for T-006 subtraction. | N/A
T-012 | Output shaft backlash measurement | Phase 1 | System | R-01 | test-campaign-rev00b.md Phase 1 | Gearbox assembled, motor shaft locked | Not Started |  |  | Backlash ≤ 0.5° (R-01 hard req) |  | Dial indicator + lever arm at 4+ positions around one revolution. | ✓
T-013 | Hand backdriving — qualitative + rough torque | Phase 1 | System | R-04 | test-campaign-rev00b.md Phase 1 | Gearbox assembled | Not Started |  |  | Backdriving torque < 1 Nm (R-04) |  | Kitchen scale + 200 mm lever arm. Quick check before powered T-008. | ✓
T-014 | Motor step response (baseline) | Phase 0 | Component | — | test-campaign-rev00b.md Phase 0 | T-009 pass | Not Started |  |  | Clean second-order response, consistent across 3–5 reps |  | Motor-only baseline for T-007 comparison. Extract tr, OS%, ts, SSE. | N/A
T-015 | Plant identification from step response data | Phase 3 | System | — | test-campaign-rev00b.md Phase 3 | T-014, T-007 complete | Not Started |  |  | Model matches measured step response within 10% |  | Fit G(s) = 1/(Js² + bs). Use torque mode for open-loop plant ID. | N/A
T-016 | Frequency response — Bode plot | Phase 3 | System | — | test-campaign-rev00b.md Phase 3 | T-015 (for validation) | Not Started |  |  | Measured Bode matches predicted from T-015 |  | Chirp or discrete sine dwell. Motor alone AND motor+gearbox overlay. | N/A
T-017 | Impedance control — virtual spring | Phase 4 | System | — | test-campaign-rev00b.md Phase 4 | T-015 (plant model for tuning) | Not Started |  |  | Linear force-displacement, smooth feel, returns to setpoint |  | Tier A: use ODrive internal PID as spring-damper. Start here. | N/A
T-018 | Impedance control — spring-damper | Phase 4 | System | — | test-campaign-rev00b.md Phase 4 | T-017 | Not Started |  |  | Damped return to setpoint, higher K achievable with B |  | Tier B: Python torque loop (~200 Hz). True impedance control. | N/A
T-019 | Variable impedance demo (stretch goal) | Phase 4 | System | — | test-campaign-rev00b.md Phase 4 | T-018 | Not Started |  |  | Smooth real-time parameter adjustment, no instability |  | Tkinter GUI with K/B sliders. Portfolio hero content. | N/A

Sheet: Unknowns Register
Unknown ID | Description | Category | Priority | Status | Linked Tests | Resolution | Date Resolved
U-01 | Planet positioning & mesh clearance — geometry vs. assembly? | Assembly/fit | Test first | Postponed → Rev 00B | T-001 | Herringbone misalignment identified as root cause. Switched to spur gears.
U-02 | (Merged into U-01) | — | — | Merged
U-03 | Lid causing drag — over-constraint on carrier? | Assembly/fit | Test first | Root cause identified | T-002 | Tolerance stackup across carrier assembly causes lid to press on carrier top. Redesign for Rev 00B. | 2026-03-13
U-04 | Carrier bearing shoulder deformation under bolt torque | Structural | Test first | Confirmed | T-003, T-005 | Shoulders sensitive to torque. Print quality issue on top carrier. Rev 00B redesign. | 2026-03-13
U-05 | Carrier halves need indexing? | Assembly/fit | Monitor/skip | Resolved | T-004 | No operational clocking load — both halves driven by same pins. | 2026-03-13
U-06 | Gearbox structural capacity (handles motor torque × 5:1?) | Structural | After fundamentals | Not Started
U-07 | Output shaft strength — self-tap holding, diameter adequate | Structural | Verify early | Known Issue |  | Known undersized → enlarged in Rev 00B design.
U-08 | Backlash — quantified | Performance | After fundamentals | Not Started | T-012
U-09 | Backdrivability — quantified | Performance | After fundamentals | Not Started | T-013, T-006, T-008
U-10 | Durability under sustained use | Degradation | After fundamentals | Not Started

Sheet: Health Log
Date | Session # | Backlash (°) | Friction Torque (Nm) | Ambient Temp (°C) | Visual Condition | Cumulative Runtime (min) | Notes
 | 1 |  |  |  |  | 0 | Initial baseline — record before first powered test

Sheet: Change Log
# | Change | Sheet(s) Affected | Details
1 | Data validation dropdowns added | Requirements, Test Log, Unknowns Register | Dropdowns on: Test Status (G), Pass/Fail (K), Req Type (E), Verification Method (G), Req Status (H), Unknown Status (E), Unknown Priority (D). Prevents typos, enforces consistent values.
2 | Coverage column auto-derived via formula | Traceability Matrix | V3:V15 now uses COUNTIF to detect P/S entries + MATCH to Requirements verification method. Conditional formatting: green=Covered, yellow=Partial, blue=Via Inspection/Demo/Analysis, red=Gap.
3 | Requirements Status auto-derived from Test Log | Requirements | H2:H14 formulas use SUMPRODUCT+SEARCH to look up linked test results. Statuses: Verified, Failed, Partial, Pending Review, Not Verified. Conditional formatting applied.
4 | Dashboard summary sheet created | Dashboard (new) | Formula-driven summary: Requirements status counts, Test campaign progress, Traceability coverage counts + gap Req IDs, Unknowns resolution status. All auto-update.
5 | Cross-reference validation column added | Test Log | Column M 'Trace Valid?' checks that Req IDs in 'Traces To' (col D) exist in Requirements!A:A. Shows ✓, ✗ Check IDs, or N/A for characterization tests.
6 | Color legend added to Traceability Matrix | Traceability Matrix | Legend in A18:B22 documents P (blue, primary), S (green, secondary), blank (no link), Char. (characterization).
7 | Health Log template improved | Health Log | Visual Condition dropdown added (Good → Needs repair). Session # auto-increments when Date is entered (B3:B50 formula). Placeholder styling cleaned up.
8 | Test level hierarchy added | Test Log, Requirements, Dashboard, Traceability Matrix | Test Log col D: Test Level (Component/Interface/Subsystem/System) with dropdown validation. Requirements col H: Verification Level with same dropdown. Dashboard: new 'Test Level Breakdown' section with COUNTIF/COUNTIFS formulas showing total & complete counts per level. Traceability Matrix: new row 2 with color-coded level labels (green=Component, gold=Interface, purple=System) + legend added.

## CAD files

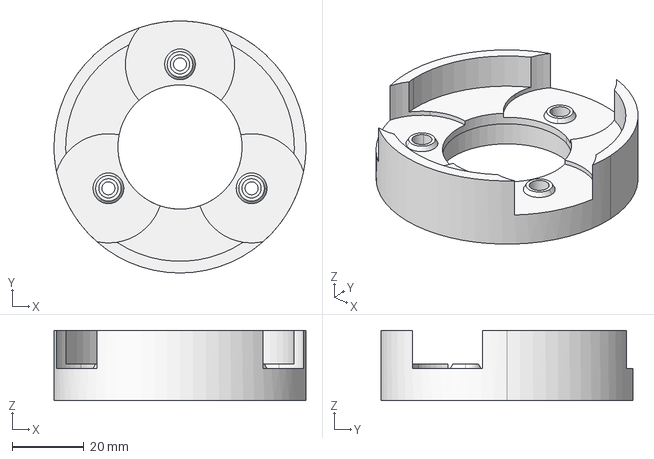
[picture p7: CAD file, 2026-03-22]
prototypes/rev00a/prints/carrier_bottom_REV00A.stp
70.0 x 70.0 x 19.5 mm

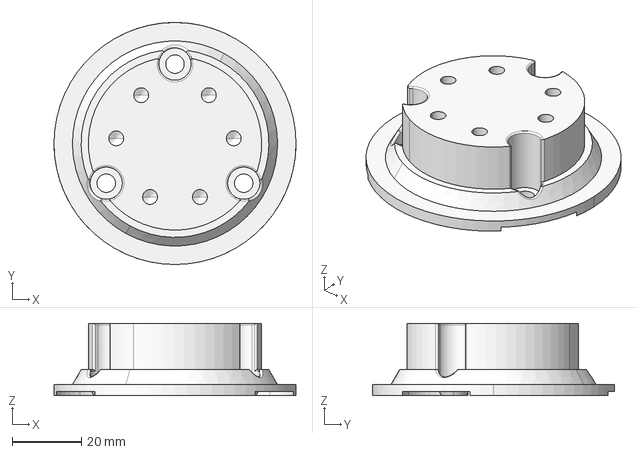
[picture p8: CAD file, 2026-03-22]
prototypes/rev00b/prints/carrier_top_REV00B_(1).stp
70.0 x 70.0 x 21.0 mm

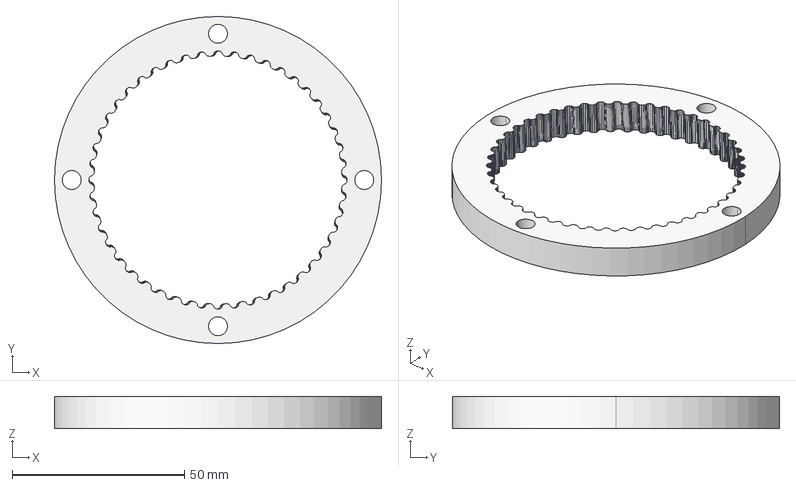
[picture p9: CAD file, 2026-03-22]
prototypes/rev00a/prints/ring_bottom.stp
95.0 x 95.0 x 9.30 mm

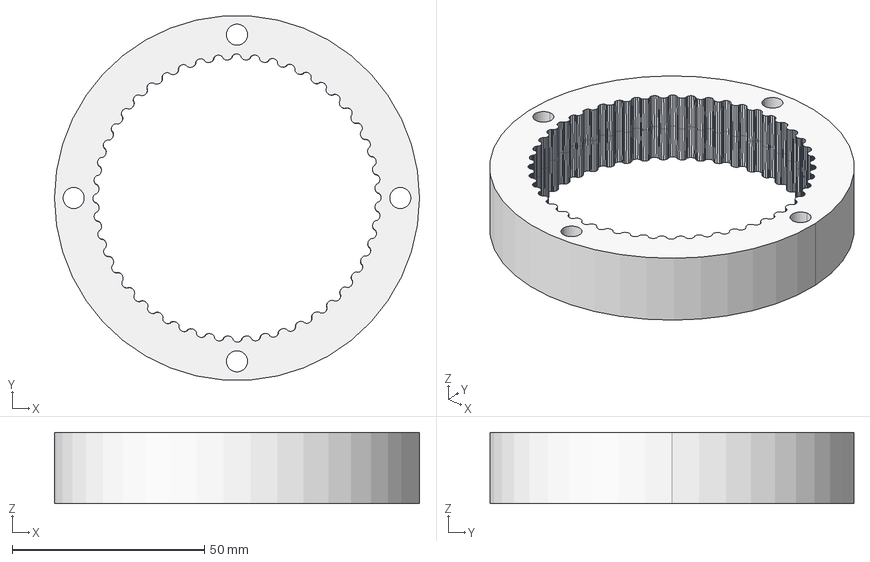
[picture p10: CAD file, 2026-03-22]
prototypes/rev00b/prints/ring_REV00B A.1.stp
95.0 x 94.7 x 18.6 mm

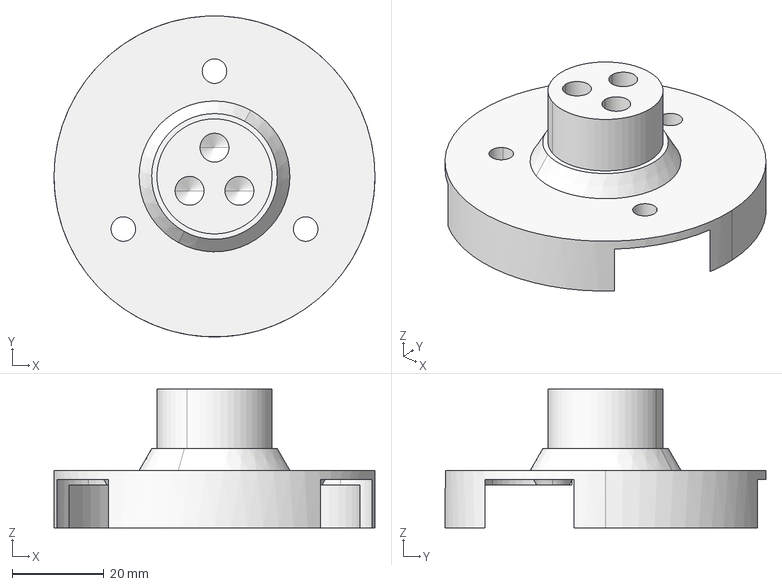
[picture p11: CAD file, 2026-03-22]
prototypes/rev00a/prints/carrier_top A.1.stp
70.0 x 70.0 x 30.2 mm

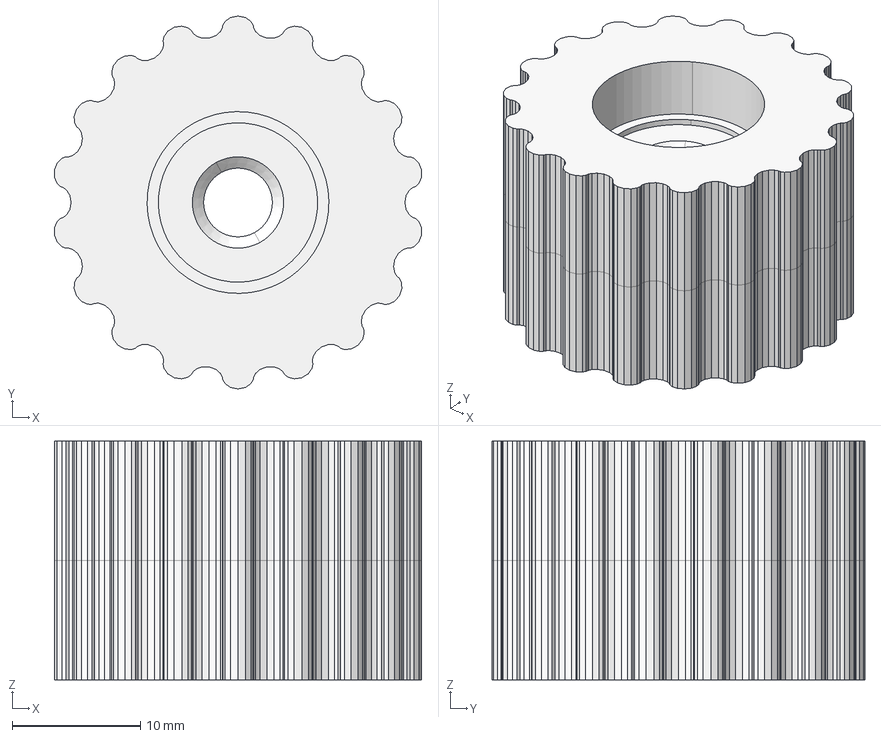
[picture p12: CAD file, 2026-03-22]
prototypes/rev00b/prints/planet_REV00B A.1_(1).stp
28.6 x 29.0 x 18.6 mm

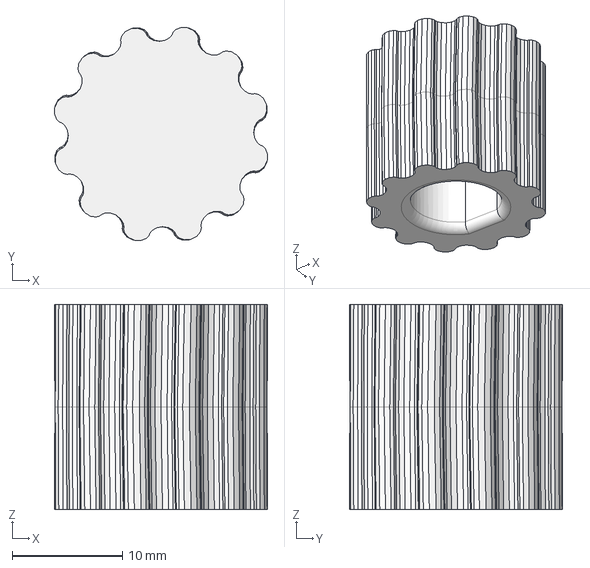
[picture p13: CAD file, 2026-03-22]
prototypes/rev00a/prints/sun_revA.stp
19.3 x 19.3 x 18.6 mm

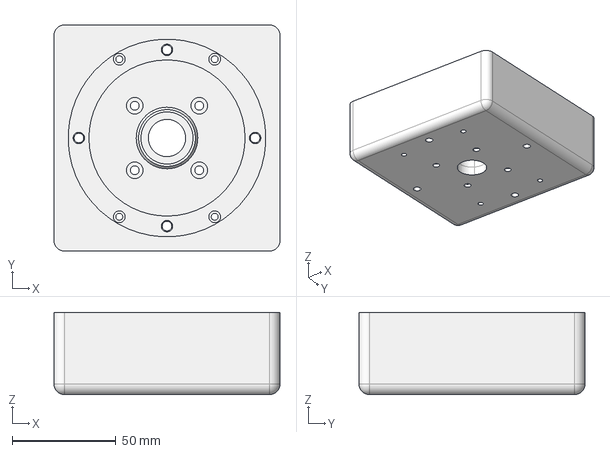
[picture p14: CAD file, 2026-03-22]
prototypes/rev00a/prints/housing_body_REV00A.stp
109.0 x 109.0 x 39.5 mm

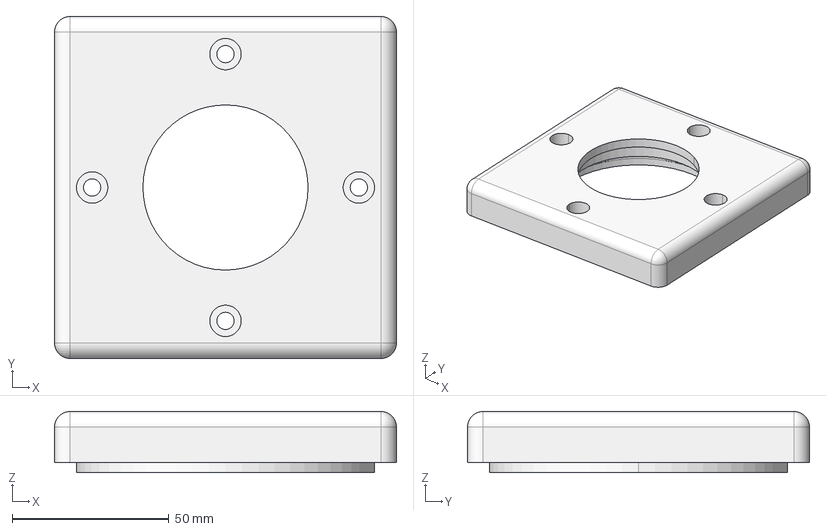
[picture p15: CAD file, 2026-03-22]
prototypes/rev00b/prints/housing_lid_REV00B.stp
109.0 x 109.0 x 19.4 mm

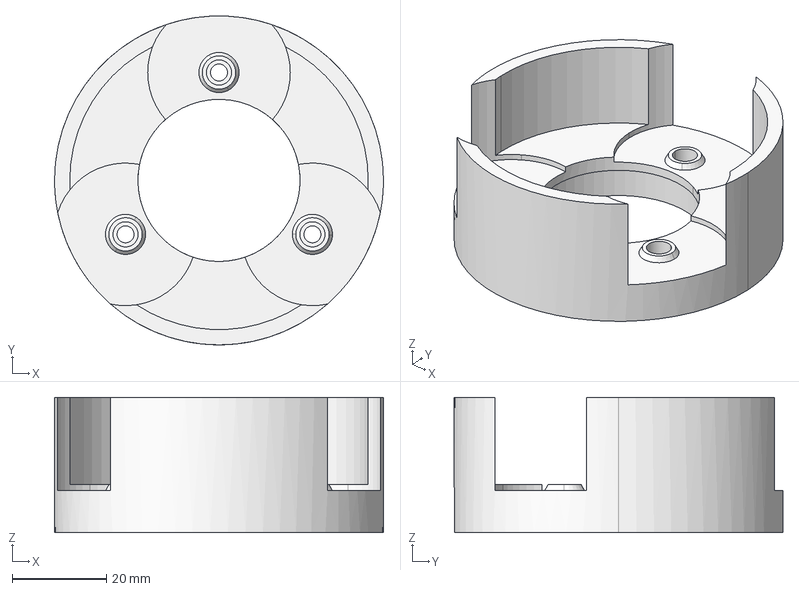
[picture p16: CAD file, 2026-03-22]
prototypes/rev00b/prints/carrier_bottom_REV00B.stp
70.0 x 70.0 x 28.8 mm

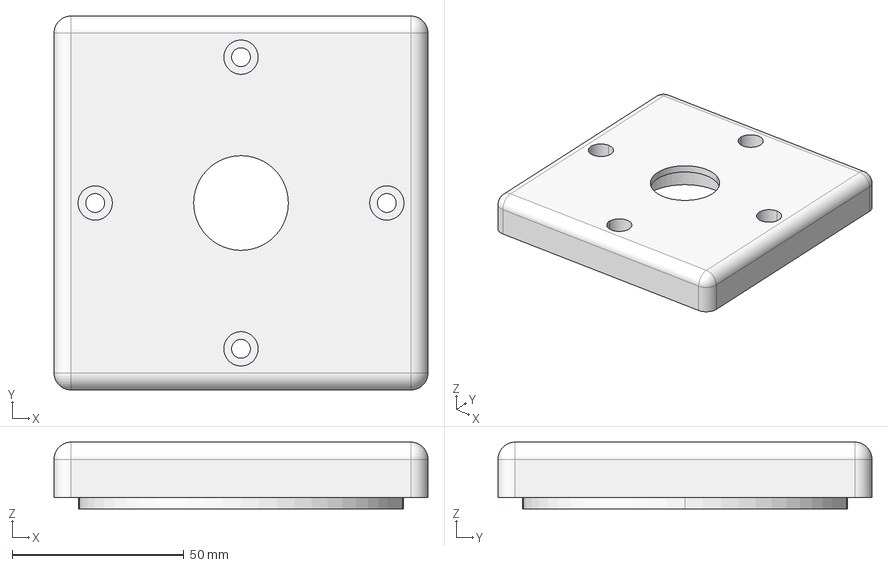
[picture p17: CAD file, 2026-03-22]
prototypes/rev00a/prints/housing_lid A.1.stp
109.0 x 109.0 x 19.4 mm

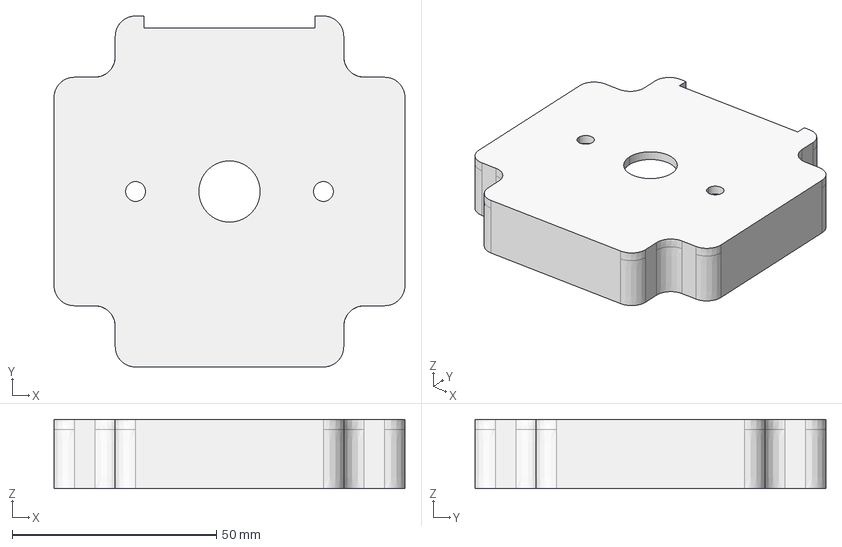
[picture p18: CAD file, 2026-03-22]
prototypes/rev00a/prints/encoder_open_housing A.1.stp
86.0 x 86.0 x 17.0 mm

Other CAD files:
prototypes/rev00b/prints/sun_REV00B A.1.stp
prototypes/rev00a/prints/ring_top.stp
prototypes/rev00a/prints/sun_REV00A-B.stp
prototypes/rev00a/prints/sun.stp
prototypes/rev00a/prints/housing_body A.1.stp
prototypes/rev00a/prints/carrier_bottom A.1.stp
prototypes/rev00a/prints/hole coupon.stp
prototypes/rev00a/prints/planet.stp

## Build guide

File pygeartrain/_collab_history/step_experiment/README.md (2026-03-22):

# STEP File Generation Experiment

This experiment converts XYZ gear profile points to STEP solid files using CadQuery.

## Results Summary

### File Size Comparison

| Gear | XYZ Files (total) | STEP File | Ratio |
|---|---|---|---|
| Sun | 20.9 KB (3 Z-levels) | 130.6 KB | 6.3x larger |
| Planet | 31.8 KB (3 Z-levels) | 192.8 KB | 6.1x larger |
| Ring | 87.1 KB (3 Z-levels) | 504.9 KB | 5.8x larger |

STEP files are larger because they contain:
- Full solid geometry (not just profiles)
- NURBS curve definitions (mathematically precise)
- B-Rep topology data

### Verification Results

All checks **PASSED**:
- Bounding box dimensions match expected values
- Ring gear: 70.02mm diameter (expected: 70mm)
- Gear thickness: 10.00mm (expected: 10mm)
- Solids are valid with proper top/bottom faces
- Geometry is symmetric about Z=0

### Visual Comparison

Side-by-side comparisons in `output/renders/` show:
- Original XYZ profiles (left) vs STEP tessellation (right)
- Tooth profiles are accurately captured
- 4-tooth sun, 6-tooth planet, 16-tooth ring all correct

## Import into 3DEXPERIENCE

### STEP Method (Recommended)
1. **File > Import > 3D Part**
2. Select `.step` file
3. Done - solid geometry imports directly

Advantages:
- One-click import
- Geometry is already a solid
- No manual lofting required
- Preserves smooth curves (NURBS)

### XYZ Method (Manual)
1. Import curves from 3 Z-level files
2. Use Loft operation to create solid
3. Requires careful profile alignment

## Files

```
step_experiment/
├── generate_step.py      # Main generator script
├── verify_step.py        # Automated verification
├── visual_compare.py     # Visual comparison tool
├── requirements.txt      # Dependencies
└── output/
    ├── sun.step          # Sun gear solid
    ├── planet.step       # Planet gear solid
    ├── ring.step         # Ring gear solid
    ├── verification_report.txt
    └── renders/
        ├── sun_comparison.png
        ├── planet_comparison.png
        └── ring_comparison.png
```

## Dependencies

- cadquery (v2.6.1)
- cadquery-ocp (OpenCASCADE bindings)
- numpy
- matplotlib (for visualization)

Install with:
```bash
pip install cadquery numpy matplotlib
```

## Verification Approach

1. **Geometric verification**: Automated checks on bounding box, thickness, face count
2. **Visual verification**: Side-by-side profile comparison
3. **Re-import test**: Load STEP back into CadQuery, extract geometry
4. **External validation**: Open in 3DEXPERIENCE or online viewer (3dviewer.net)

## Limitations Found

1. **Tessellation resolution**: The spline approximation uses CadQuery's default tolerance. Very fine details might lose some precision.

2. **Ring gear**: Currently exports as a solid disc with gear profile. For a true ring gear, you'd need to:
   - Create the outer profile
   - Boolean subtract the inner bore

3. **Assembly**: Planet gears need to be patterned manually in CAD (use planet_centers.txt for positions)

## How Verification Works

The verification script:
1. Loads each STEP file back into CadQuery
2. Extracts bounding box dimensions
3. Compares against expected values from gearset_info.txt
4. Tessellates the top face and extracts boundary points
5. Creates visual comparison with original XYZ data

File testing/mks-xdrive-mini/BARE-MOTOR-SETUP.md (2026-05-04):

# MKS XDrive Mini + D6374 Bare-Motor Bring-Up

> Purpose: get the `D6374 150KV` spinning safely on the `MKS XDrive Mini v1`, then connect that bench setup to the `Hammer H2` trainer for dyno work.

## What Changed

The old QDD hardware notes were written around the larger ODrive 3.6 board. The current controller is the smaller `MKS XDrive Mini v1`, which is ODrive-like but not a drop-in "upgrade firmware and forget it" board.

Key implications:

- Treat the board as legacy ODrive `v0.5.1` hardware
- Do not use generic `odrivetool upgrade`
- Do first bring-up over USB, not CAN
- Ignore multi-axis CAN quirks until the motor spins reliably on `axis0`

## Bench Plan

1. Bring up the XDrive Mini on USB only
2. Confirm encoder feedback is sane
3. Spin the bare motor at low speed
4. Add the H2 data path separately
5. Couple motor to trainer only after both sides work independently

## Hardware Needed

- `MKS XDrive Mini v1`
- `D6374 150KV` motor
- encoder path:
  - preferred: AS5047 SPI encoder path if you have the Makerbase-compatible encoder board and magnet setup
  - fallback: incremental A/B/Z encoder with known CPR
- current-limited DC supply
- brake resistor
- USB-C data cable for the XDrive Mini
- rigid motor fixture
- emergency power kill within arm's reach

## Encoder Reality Check

You need a real encoder before this becomes a servo test.

Current confirmed encoder for this bench:

- `CUI AMT 102-V`
- treat it as an incremental encoder path
- default working assumption: `8192 CPR`

- The XDrive Mini schematic shows support for an `AS5047` SPI encoder path and also an incremental encoder header.
- The community config you linked assumes:
  - `ENCODER_MODE_SPI_ABS_AMS`
  - `abs_spi_cs_gpio_pin = 7`
  - `cpr = 16384`
- If your D6374 does not currently have a mounted encoder and magnet, stop there first. No encoder means no normal ODrive-style closed-loop bring-up.

## Software Recommendation

Use a dedicated Python environment for the XDrive Mini so you do not mix it with the older ODrive 3.6 tooling.

```powershell
Set-Location C:\Users\aaron\Documents\c-projects\qdd-gearbox\testing\mks-xdrive-mini
C:\Users\aaron\miniconda3\python.exe -m venv .venv-odrive051
.venv-odrive051\Scripts\Activate.ps1
python -m pip install --upgrade pip
python -m pip install odrive==0.5.1.post0 libusb-package bleak matplotlib
```

Reason:

- the community guide explicitly targets `odrive==0.5.1.post0`
- the XDrive Mini ships with Makerbase-modified `v0.5.1` firmware
- newer generic firmware and tooling may connect poorly or brick the board if you start "upgrading"
- on Windows, `libusb-package` is needed so PyUSB has a backend for the native interface

In this workspace, the sprint wrappers already handle this through:

- `testing/mks-xdrive-mini/mks-python-env.ps1`

## Firmware Rules

- Keep the board on the Makerbase `v0.5.1` family firmware unless you intentionally reflash with `ST-Link`
- Do not run `odrivetool dfu`, `upgrade`, or generic ODrive firmware update flow
- If the board gets bricked, recover with `ST-Link V2` and the Makerbase dump, not stock ODrive binaries

Makerbase's own repo currently includes:

- `MKS_ODrive_MINI_0_5_1_20250326.bin`
- `MKS ODRIVE MINI V1.0 Schematic.pdf`
- a note stating the Mini needs source modifications beyond plain ODrive v3.6 code

## Wiring Notes

Minimum bench wiring:

- DC supply to board power input
- brake resistor connected
- three motor phases connected to `axis0` motor output
- encoder connected and secured
- USB connected to laptop

Treat the board like classic ODrive hardware here:

- correct polarity matters
- loose motor leads will create garbage behavior fast
- bench supplies usually do not safely absorb regen, so keep the brake resistor installed

## First Bring-Up

### 1. Confirm USB connection

```powershell
.venvs\xdrive-mini\Scripts\Activate.ps1
python -c "import odrive; odrv0 = odrive.find_any(timeout=10); print(odrv0.serial_number)"
```

If this does not enumerate, solve USB/driver issues before touching motor config.

### 2. Read current firmware/config state

```python
import odrive
odrv0 = odrive.find_any(timeout=10)

print(odrv0.vbus_voltage)
print(odrv0.axis0.current_state)
print(odrv0.axis0.error)
print(odrv0.axis0.motor.error)
print(odrv0.axis0.encoder.error)
```

### 3. Only erase config if you intentionally want a clean start

The community config begins with `erase_configuration()`. That is fine for a deliberate fresh setup, but it is not a casual first command.

### 4. Set the bare minimum motor parameters

Start from the linked community flow, but replace the motor-specific values with your hardware:

```python
odrv0.config.brake_resistance = 2.0
odrv0.config.dc_bus_undervoltage_trip_level = 8.0
odrv0.config.dc_bus_overvoltage_trip_level = 56.0
odrv0.config.dc_max_positive_current = 20.0
odrv0.config.dc_max_negative_current = -3.0
odrv0.config.max_regen_current = 0

odrv0.axis0.motor.config.pole_pairs = 7
odrv0.axis0.motor.config.calibration_current = 5
odrv0.axis0.motor.config.resistance_calib_max_voltage = 2
odrv0.axis0.motor.config.motor_type = MOTOR_TYPE_HIGH_CURRENT
odrv0.axis0.motor.config.current_lim = 10
odrv0.axis0.motor.config.requested_current_range = 20
```

Notes:

- `pole_pairs = 7` matches the existing QDD D6374 notes
- keep `current_lim` conservative at first
- if the motor fails to calibrate, do not just keep increasing current blindly

### 5. Set encoder mode correctly

If using the AS5047 SPI path:

```python
odrv0.axis0.encoder.config.mode = ENCODER_MODE_SPI_ABS_AMS
odrv0.axis0.encoder.config.abs_spi_cs_gpio_pin = 7
odrv0.axis0.encoder.config.cpr = 16384
odrv0.axis0.encoder.config.bandwidth = 3000
odrv0.axis0.encoder.config.calib_range = 10
```

If using an incremental encoder instead, do not copy the SPI settings. Set:

- incremental mode
- correct CPR for the encoder you actually mounted

### 6. Save, reboot, calibrate

```python
odrv0.save_configuration()
odrv0.reboot()
```

Reconnect, then:

```python
odrv0.axis0.requested_state = AXIS_STATE_MOTOR_CALIBRATION
```

After that passes cleanly, run the encoder calibration path appropriate to your encoder setup.

### 7. First motion command

Do not jump straight to aggressive position control. Start in velocity mode at a very low speed.

```python
odrv0.axis0.requested_state = AXIS_STATE_CLOSED_LOOP_CONTROL
odrv0.axis0.controller.config.control_mode = CONTROL_MODE_VELOCITY_CONTROL
odrv0.axis0.controller.input_vel = 0.5
```

If the motor behaves correctly:

- stop
- inspect temperatures, sounds, and errors
- then increase speed in small steps

## CAN Notes

Ignore CAN until USB bring-up is done.

When you do move to CAN:

- set `axis0` to the node ID you want
- move the ghost `axis1` to `63`

```python
odrv0.axis0.config.can_node_id = 0
odrv0.axis1.config.can_node_id = 63
odrv0.can.set_baud_rate(500000)
```

This only matters for CAN. It is not needed for simple USB bench testing.

## Hammer H2 Data Path

The H2 should be treated as a second subsystem. Keep the split clear:

- hardware/test concept: `testing/dyno/README.md`
- executable BLE capture tool: `testing/dyno/ble-capture/`

Validate it independently first:

```powershell
Set-Location C:\Users\aaron\Documents\c-projects\qdd-gearbox\testing\\dyno\\ble-capture
C:\Users\aaron\miniconda3\python.exe dyno.py scan
C:\Users\aaron\miniconda3\python.exe dyno.py capture --duration 20 --output runs\smoke_h2.csv
```

Important:

- your local H2 tooling uses BLE Cycling Power Service, not FTMS
- BLE notifications are about `~1.1 Hz`, so use trainer data for steady-state dyno work, not fast transients
- the trainer freehub is one-way, so the loaded dyno direction matters

## Recommended Bench Sequence

1. XDrive Mini + motor + encoder only
2. H2 BLE scan/capture only
3. print/test freehub adapter
4. couple bare motor to trainer
5. run a no-load spin with the trainer mechanically connected but electrically passive
6. run low-speed, low-current dyno capture

## Helper Script

There is now a dedicated first-spin helper at:

- `testing/mks-xdrive-mini/xdrive_first_spin.py`

Example for an AMT-102 style incremental encoder:

```powershell
& "C:\Users\aaron\Documents\c-projects\qdd-gearbox\testing\mks-xdrive-mini\.venv-odrive051\Scripts\python.exe" `
  "C:\Users\aaron\Documents\c-projects\qdd-gearbox\testing\mks-xdrive-mini\xdrive_first_spin.py" `
  --configure `
  --profile bare `
  --encoder incremental `
  --cpr 8192 `
  --calibrate full `
  --spin `
  --velocity-tps 0.5 `
  --spin-duration 3
```

Example for an AS5047 SPI encoder path:

```powershell
& "C:\Users\aaron\Documents\c-projects\qdd-gearbox\testing\mks-xdrive-mini\.venv-odrive051\Scripts\python.exe" `
  "C:\Users\aaron\Documents\c-projects\qdd-gearbox\testing\mks-xdrive-mini\xdrive_first_spin.py" `
  --configure `
  --profile bare `
  --encoder spi_ams `
  --cpr 16384 `
  --abs-spi-cs-gpio-pin 7 `
  --calibrate full `
  --spin `
  --velocity-tps 0.5 `
  --spin-duration 3
```

## Known Limit — Bare Motor on Hammer Trainer (2026-05-03)

The bare D6374 cannot drive the Hammer trainer's loaded direction at this controller's effective `~70 A` Iq cap. Confirmed by a 150 s pinned-current run: motor delivered the full commanded `2.8 Nm`, encoder velocity stayed at `0`, motor heated `+9 °C`, and `232 W` of input power dissipated entirely as heat. Iq saturated at the cap throughout.

Practical implications when bringing up bare-motor again:

- **Direction asymmetry is real.** Negative motor velocity = freewheel direction (low load, easy to drive at small currents — confirmed working in session 006). Positive = loaded direction (cannot be driven bare-motor without one of the workarounds below).
- **Do not pin Iq at the cap in the loaded direction for more than ~30 s without rotation.** It's a pure-resistive heater at that point. Motor and FET will rise toward thermal abort.
- **For matched-load (Hammer-recording) bare-motor data, choose one:**
  - hand-spin the wheel during the run to break stiction; motor maintains at lower steady-state torque
  - try a higher-current burst (`100–120 A` peak, `≤ 10 s`, strict thermal abort) if you accept the windings stress
  - change methodology — characterize bare motor in freewheel direction at low load, gearbox-installed in loaded direction; infer gearbox-only efficiency from motor losses

The 5:1 gearbox exists *because* the bare motor doesn't have enough torque to drive these loads. See [`testing/data/session-008-bare-baseline-handoff.md`](../data/session-008-bare-baseline-handoff.md) for the full diagnosis.

## Recovery From Sticky Axis Errors

The synced harness (`safe_ramp_test.py`, `safe_torque_ramp_test.py`) now does:

1. Disable watchdog → `odrv.clear_errors()` → per-target `error = 0` → print post-clear state.
2. Re-enable watchdog → immediately `watchdog_feed()` → `clear_errors()` again → transition to `CLOSED_LOOP`.
3. Inside the run loop, check `current_state` each tick; if it drops out of `CLOSED_LOOP`, print `disarm_reason` + `active_errors` + per-subobject errors and abort cleanly.

This handles the sticky-error chain seen during 2026-05-03 (bits `2048` WATCHDOG_TIMER_EXPIRED, `48`, `16`).

If the script still prints `FAILED to enter closed loop` and the post-clear printout shows nonzero axis error: **power-cycle the PSU** (off, count to 5, on). Software clear cannot reset some sticky bits without a controller power cycle.

## Immediate Unknowns To Close

- Do you already have the Makerbase-compatible AS5047 board and magnet, or are you using another encoder?
- What DC supply and brake resistor are you using with the XDrive Mini?
- Do you want USB-only bench control first, or are you planning to go straight to CAN + Arduino/ESP32?

## Sources

- Hackaday project: [MKS XDrive Mini Guide: Set up, Tuning & Arduino](https://hackaday.io/project/204985-mks-xdrive-mini-guide-set-up-tuning-arduino)
- Community repo: [justlovescience/MKS-XDRIVE-MINI](https://github.com/justlovescience/MKS-XDRIVE-MINI)
- Makerbase firmware/schematic repo: `C:\Users\aaron\Documents\c-projects\.tmp\mks-odrive`
- H2 local tooling: `C:\Users\aaron\Documents\c-projects\saris-h2-dyno`

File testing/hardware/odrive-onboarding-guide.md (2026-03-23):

---
created: 2026-03-22
tags: [motor-control, odrive, onboarding, safety]
---

# ODrive 3.6 + D6374 Onboarding Guide

Everything you need to get the motor spinning from a cold start. Written from hard-won troubleshooting — read this before powering anything on.

## Safety First

> [!danger] Mandatory Safety Rules
> - **Never touch motor leads or encoder wires while powered on.** 55V DC can kill. Motor phase voltages spike during braking.
> - **Secure the motor before spinning.** The D6374 generates over 1 Nm of torque and can throw itself off a bench. Clamp or bolt it down.
> - **Keep hands and cables clear of the rotor.** At 5 t/s (300 RPM) the exposed shaft is a finger-catching hazard. At high speed (6000+ RPM in torque mode) it's genuinely dangerous.
> - **The brake resistor gets hot.** 50W dissipation during hard stops. Don't touch it during or after decel tests.
> - **The power supply can source dangerous current.** Our supply runs ~55V and can push well beyond 19A at the wall. Treat it like a welding source.
> - **If anything sounds wrong, cut power at the supply.** Don't try to software-stop a desync'd motor — it may spike current instead.

### Electrical Limits

| Parameter | Limit | What Happens If Exceeded |
|---|---|---|
| Bus voltage | 59V trip | ODrive shuts down (overvoltage fault) |
| Motor current | 19A (software limit) | ODrive current-limits or faults |
| Motor phase R | ~50 mOhm | If reads <10 mOhm or NaN → corrupted, motor won't respond correctly |
| Motor phase L | ~23 uH | Same — corruption check |
| Max stable velocity (PID) | ~5 t/s (300 RPM) | Above this, velocity PID oscillates and loses control |
| FOC desync limit | ~50 t/s (3000 RPM) | Commutation fails, motor stalls violently, high current spike |
| Cogging breakaway | ~1.9A (~0.105 Nm) | Below this current the motor just sits in a detent and vibrates |

---

## Hardware Wiring & Pre-Power Checklist

> [!danger] The ODrive 3.6 has NO reverse polarity protection. Wiring DC power backwards will fry the board instantly.

### Connection Diagram

```
                    ┌──────────────────────────────────┐
   DC SUPPLY        │         ODrive 3.6               │
   (+) ────────────►│ DC+ (thick screw terminal)       │
   (-) ────────────►│ DC- (thick screw terminal)       │
                    │                                  │
   BRAKE RESISTOR   │ AUX (2-pin screw terminal)       │
   (2Ω 50W) ◄─────►│ Polarity doesn't matter           │
                    │                                  │
   D6374 MOTOR      │ M0 (3x screw terminal)           │
   Phase A ────────►│ A                                │
   Phase B ────────►│ B                                │
   Phase C ────────►│ C                                │
                    │                                  │
   AMT-102 ENCODER  │ J4 encoder port (JST-SH)        │
   (ribbon cable)──►│ Keyed connector, one way only    │
                    │                                  │
   USB ────────────►│ Micro-USB                        │
                    └──────────────────────────────────┘
```

### Pre-Power Checklist

Run through this **every time** before turning on the power supply:

> [!warning] Hardware Checklist
> - [ ] **DC polarity correct.** Red/positive to DC+, black/negative to DC-. Triple-check. No reverse protection on this board.
> - [ ] **Screw terminals tight.** Loose DC connections arc and melt. Loose motor phase wires cause intermittent faults. Wiggle each wire — it shouldn't move.
> - [ ] **Brake resistor connected and not shorting anything.** Both wires into the AUX terminal. If disconnected, regen energy has nowhere to go → overvoltage fault → ODrive shuts down mid-decel. The resistor body is metal — make sure it's not bridging exposed contacts or bare wires. It only gets hot during hard decel at high speeds.
> - [ ] **Motor bolted down.** Clamped or mounted. Not sitting loose on the bench.
> - [ ] **Encoder sleeve tight on shaft.** Grab it and twist by hand. If it rotates, press it back on. Slip = garbage position data = failed cal or mid-run faults.
> - [ ] **Encoder cable seated.** Push the JST connector into J4 until it clicks. It's keyed — only goes one way.
> - [ ] **Gearbox state matches your PID gains.** If gearbox is attached, you need gearbox gains. If bare motor, you need bare motor gains. Wrong gains = oscillation or stall. See [[#PID Gains — Which Config Are You Running?]].
> - [ ] **Nothing touching the rotor.** Cables, zip ties, fingers, sleeves — clear of the spinning parts.
> - [ ] **Power supply current limit set.** If your supply has an adjustable current limit, set it to ~5A for initial bring-up. You can raise it once things are working.
> - [ ] **USB connected.** Plug in before or after DC power — order doesn't matter for ODrive 3.6.

### Motor Phase Order

The 3 motor wires (A, B, C) can go into the 3 ODrive terminals in any order. Wrong order just reverses rotation direction — it won't damage anything. If the motor spins the wrong way after calibration:

1. Power off
2. Swap any two of the three motor wires
3. Recalibrate (state 3)

### AMT-102 Encoder DIP Switches

The encoder ships at 2048 PPR (x4 = 8192 CPR). **Leave all DIP switches at factory default.** The ODrive config expects `cpr = 8192`. If someone has changed the DIP switches, the encoder CPR won't match and calibration will fail or give wrong velocity readings.

---

## Hardware on the Bench

| Component | Spec | Notes |
|---|---|---|
| ESC | ODrive 3.6 (FW 0.5.5, HW 3.6.56) | **End-of-life hardware** — no firmware updates coming |
| Motor | D6374 150kv, 7 pole pairs | Star-wound, exposed shaft |
| Encoder | CUI AMT-102 (8192 CPR) | Press-fit sleeve on shaft — check tightness before every session |
| Gearbox | 5:1 planetary (removable) | Adds friction/damping, changes PID gains needed |
| Brake resistor | 50W, 2 ohm | Must be armed via full calibration (state 3) |
| Power supply | ~55V DC | Current draw at the supply is much lower than motor phase current (the ESC trades voltage for current) |

---

## First-Time Setup (One-Time)

### 1. Install USB Driver (Zadig)

The ODrive 3.6 won't show up in Python without the right driver.

1. Download and open [Zadig](https://zadig.akeo.ie/)
2. Options → List All Devices
3. Select **"ODrive 3.6 Native Interface (Interface 2)"**
4. Set driver to **WinUSB** → Install
5. Reboot if needed

> [!warning] After a factory reset (`erase_configuration()`), you'll need to redo this step.

### 2. Install Python Packages

```bash
pip install odrive==0.5.5
```

That's it. The `odrive` package includes `odrivetool` (interactive shell) and the Python API.

### 3. Verify Connection

```python
import odrive
odrv0 = odrive.find_any(timeout=10)
print(f"Bus voltage: {odrv0.vbus_voltage:.1f}V")
print(f"Serial: {odrv0.serial_number}")
```

Should print ~55V and the serial `59962984378673`. If it hangs, check Zadig driver.

> [!warning] Only one process can hold the USB connection at a time.
> Close `odrivetool` before running Python scripts, and vice versa.

---

## Every-Session Startup

The encoder loses its reference on every power cycle. You must recalibrate.

### Step 1: Power on and connect

```python
import odrive
odrv0 = odrive.find_any()
print(f"Bus: {odrv0.vbus_voltage:.1f}V, State: {odrv0.axis0.current_state}")
# State should be 1 (IDLE)
```

### Step 2: Full calibration (state 3)

```python
odrv0.axis0.requested_state = 3   # FULL_CALIBRATION_SEQUENCE
```

The motor will beep (measuring R and L), then spin slowly (encoder offset search). Wait until state returns to 1 (IDLE).

> [!danger] Use state 3 (full cal), NOT state 7 (encoder-only)
> Encoder-only calibration (state 7) does **not** arm the brake resistor. If you skip the brake resistor arming and then decelerate hard, the bus voltage spikes and the ODrive faults with overvoltage. This is an undocumented FW 0.5.5 behavior. **Always use state 3.**

### Step 3: Check for motor parameter corruption

```python
R = odrv0.axis0.motor.config.phase_resistance
L = odrv0.axis0.motor.config.phase_inductance
print(f"R = {R*1000:.1f} mOhm, L = {L*1e6:.1f} uH")
```

**Expected:** R ≈ 48-52 mOhm, L ≈ 22-24 uH

If R < 10 mOhm or L shows NaN → params are corrupted. See [[#Motor Parameter Corruption Fix]] below.

### Step 4: Enter closed-loop control

```python
odrv0.axis0.requested_state = 8   # CLOSED_LOOP_CONTROL
```

Motor is now holding position. You can command it.

### Step 5: Command motion

```python
# Velocity mode
odrv0.axis0.controller.config.control_mode = 2  # VEL_CONTROL
odrv0.axis0.controller.input_vel = 2.0  # turns/sec

# Stop
odrv0.axis0.controller.input_vel = 0

# Position mode
odrv0.axis0.controller.config.control_mode = 3  # POS_CONTROL
odrv0.axis0.controller.input_pos = 10.0  # turns

# Torque mode (be careful)
odrv0.axis0.controller.config.control_mode = 1  # TORQUE_CONTROL
odrv0.axis0.controller.input_torque = 0.1  # Nm
```

### Step 6: Shut down safely

```python
odrv0.axis0.requested_state = 1   # IDLE
```

Then power off the supply.

---

## PID Gains — Which Config Are You Running?

**You must switch gains when adding/removing the gearbox.** Using gearbox gains on a bare motor causes violent oscillation.

| Config | pos_gain | vel_gain | vel_integrator_gain | vel_ramp_rate |
|---|---|---|---|---|
| Bare motor (no gearbox) | 5.0 | 0.05 | 0.05 | 3.0 |
| 5:1 gearbox | 15.0 | 0.1 | 0.2 | 10.0 |

```python
# Example: set bare motor gains
ax = odrv0.axis0
ax.controller.config.pos_gain = 5.0
ax.controller.config.vel_gain = 0.05
ax.controller.config.vel_integrator_gain = 0.05
ax.controller.config.vel_ramp_rate = 3.0
```

> [!warning] Gearbox needs vel_ramp_rate ≥ 10
> At 3 t/s/s (bare motor default), the integrator saturates at current limit before the gearbox breaks through stiction. The motor just buzzes and doesn't move.

---

## Troubleshooting

### Motor Parameter Corruption Fix

Full cal (state 3) sometimes corrupts R and L even with `pre_calibrated=True`. Symptoms: motor doesn't respond to commands, or current controller behaves erratically.

```python
# 1. Disable pre_calibrated
odrv0.axis0.motor.config.pre_calibrated = False

# 2. Run motor-only cal (state 4) — NOT full cal
odrv0.axis0.requested_state = 4
# Wait for IDLE

# 3. Verify
R = odrv0.axis0.motor.config.phase_resistance
L = odrv0.axis0.motor.config.phase_inductance
print(f"R = {R*1000:.1f} mOhm, L = {L*1e6:.1f} uH")
# Should be R ≈ 48-52, L ≈ 22-24

# 4. Re-enable and save
odrv0.axis0.motor.config.pre_calibrated = True
odrv0.save_configuration()
# ODrive reboots here (DeviceLostException is normal)
```

### Brake Resistor Not Armed

If you get overvoltage faults during decel, the brake resistor probably isn't armed.

```python
print(odrv0.config.enable_brake_resistor)   # Should be True
print(odrv0.config.brake_resistance)         # Should be 2.0
```

`enable_brake_resistor` can silently reset after `save_configuration()`. Verify after every reboot. Fix: set it True and save again.

### Motor Won't Move / Buzzes in Place

Check in this order:
1. **State check:** `odrv0.axis0.current_state` — must be 8 (closed-loop). If 1, you forgot to enter closed-loop.
2. **Error check:** `odrv0.axis0.error`, `odrv0.axis0.motor.error`, `odrv0.axis0.encoder.error` — any non-zero means something faulted.
3. **R/L corruption:** Check phase_resistance and phase_inductance (see above).
4. **Cogging detent:** At currents below ~1.9A (0.105 Nm), the motor just sits in a magnet detent. Command more torque.
5. **Wrong gains:** If you have gearbox gains on a bare motor, it will oscillate and fault.

### Clear All Errors

```python
odrv0.axis0.error = 0
odrv0.axis0.motor.error = 0
odrv0.axis0.encoder.error = 0
odrv0.axis0.controller.error = 0
```

### save_configuration() Reboots the ODrive

This is normal. You'll get a `DeviceLostException`. Reconnect:

```python
odrv0 = odrive.find_any()
```

### Factory Reset

Nuclear option. Erases everything.

```python
odrv0.erase_configuration()
# ODrive reboots. You'll need to:
# 1. Redo Zadig driver install
# 2. Reconfigure all parameters from scratch
```

### Encoder Slip

The AMT-102 press-fit sleeve can slip on the shaft during high-accel tests. Symptoms: position drifts, calibration fails, or motor faults mid-run. **Check the sleeve tightness before every session** — twist it by hand and make sure it doesn't rotate.

---

## Saved Configuration Reference

These are the values currently saved to the ODrive. If you factory reset, re-enter all of these:

```python
odrv0.config.dc_bus_overvoltage_trip_level = 59.0
odrv0.axis0.motor.config.current_lim = 19.0
odrv0.axis0.motor.config.calibration_current = 10.0
odrv0.axis0.motor.config.pole_pairs = 7
odrv0.axis0.motor.config.phase_resistance = 0.05022
odrv0.axis0.motor.config.phase_inductance = 23.14e-6
odrv0.axis0.motor.config.pre_calibrated = True
odrv0.axis0.encoder.config.cpr = 8192
odrv0.axis0.encoder.config.mode = 0  # INCREMENTAL
odrv0.config.enable_brake_resistor = True
odrv0.config.brake_resistance = 2.0
odrv0.axis0.trap_traj.config.vel_limit = 5.0
odrv0.axis0.trap_traj.config.accel_limit = 10.0
odrv0.axis0.trap_traj.config.decel_limit = 10.0
odrv0.save_configuration()
```

---

## Tools & Scripts

| What | Command | Notes |
|---|---|---|
| Interactive shell | `odrivetool` | Tab-complete, live object model. Good for poking around. |
| Live dashboard | `python _dev/odrive_dashboard.py` | Tkinter GUI: voltage, current, velocity, position at 20Hz |
| Characterization sweep | `python _dev/odrive_sweep.py "no_gearbox"` | Runs 6 automated tests, saves JSON results |
| Compare sweeps | `python _dev/odrive_compare.py` | Plots side-by-side comparison from saved JSONs |

---

## Things That Will Bite You (Lessons Learned)

1. **State 7 doesn't arm the brake resistor.** Use state 3. Always.
2. **Full cal corrupts motor params randomly.** Check R and L after every calibration. The sweep script does this automatically with retries.
3. **PID gains are config-specific.** Gearbox gains on bare motor = violent oscillation. Bare motor gains on gearbox = motor buzzes and doesn't move.
4. **Ramp rate matters more than you think.** Too slow and the integrator saturates. Too fast and the motor can't track. Bare motor sweet spot: ~6.7 t/s/s. Gearbox needs ≥ 10 t/s/s.
5. **Velocity PID tops out at ~5 t/s on this firmware.** The motor can go way faster (6000+ RPM in torque mode), but the velocity controller can't track above ~300 RPM. This is a FW 0.5.5 limitation.
6. **Power supply current ≠ motor current.** The ESC is a DC-AC converter. You might see 2A at the supply but 15A in the motor phases. Don't be surprised.
7. **Only one USB connection at a time.** Close odrivetool before running scripts. Close scripts before opening odrivetool.
8. **save_configuration() reboots.** DeviceLostException after save is normal.
9. **The gearbox clicks at high accel.** Not broken, just gear mesh noise.
10. **The encoder sleeve slips.** Check it before every session. If position drifts randomly, this is probably why.

---

## Quick Reference Card

```
CALIBRATE:    odrv0.axis0.requested_state = 3
CLOSED LOOP:  odrv0.axis0.requested_state = 8
IDLE:         odrv0.axis0.requested_state = 1
VELOCITY:     .controller.config.control_mode = 2 → .controller.input_vel = X
POSITION:     .controller.config.control_mode = 3 → .controller.input_pos = X
TORQUE:       .controller.config.control_mode = 1 → .controller.input_torque = X
CHECK ERRORS: .axis0.error, .motor.error, .encoder.error
CHECK PARAMS: .motor.config.phase_resistance, .phase_inductance
BUS VOLTAGE:  odrv0.vbus_voltage
```

---

## Where to Find More

- **Full hardware spec, sweep data, VESC transition notes:** [[odrive-motor-control|README]]
- **Structured test plan and characterization framework:** [[Motor Test Matrix]]
- **ODrive docs (FW 0.5.5):** [docs.odriverobotics.com](https://docs.odriverobotics.com/v/0.5.5/)

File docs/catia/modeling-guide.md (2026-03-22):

# CATIA Modeling Guide — QDD Gearbox

*Living document. Add to this as you model. Quick reference for "how does this work?" moments.*

---

## Principles

Core rules that keep the assembly clean and maintainable.

### Single Source of Truth
All positioning data lives in the skeleton. Parts don't define their own locations — they read from skeleton geometry.

### Constraint Rule
**Parts constrain to skeleton, never to each other.**

If Part A and Part B need to align, they both reference the same skeleton geometry. This prevents fragile chains where moving one part breaks another.

### B-Rep Free Rule
**Never reference edges or faces of solid bodies.** Sketch on Planes and reference Skeleton wireframes (axes, points, curves) instead. B-Rep (boundary representation) references break when features reorder or geometry regenerates. If you need a position, publish a point or plane from the skeleton — not a face of a pad.

### Clean Publication Rule
Don't publish an entire Sketch. Use `Extract` or `Output Features` to publish only the specific curves/points needed. Other parts should only see the interface, not the internals.

### Pattern Rule
Use the skeleton's center axis for angular patterns. The skeleton publishes the number of instances (e.g., number of planets), and patterns reference that.

**Body-level patterning is more stable than feature-level.** Pattern the entire Body (containing the feature), not the individual Pad/Pocket. Feature-level patterns can break when upstream geometry changes.

### Placeholder Philosophy
Placeholder gears are "geometric contracts" — they define the interface (pitch diameter, position) without the complexity of real tooth geometry. When real gears are ready, they swap in and inherit the same constraints.

---

## Workarounds

CATIA quirks and their solutions. Add new ones as you discover them.

### Sketches Don't Support Circular Patterns
**Problem:** You can't circular-pattern geometry within a sketch in CATIA.

**Solution:** Pattern at the part or assembly level instead. Create the base feature from the sketch, then use Circular Pattern on the resulting geometry.

### Sketch H/V Axis Is Local, Not Global
**Problem:** The H and V axes in the sketcher are arbitrary local axes — they don't necessarily align with the global X, Y, or Z.

**Solution:** Always reference the global X/Y/Z directions explicitly. Use Positioned Sketches (see below) to control orientation.

### Positioned Sketch Setup
**Problem:** Default sketches can end up with unexpected orientation, causing geometry surprises.

**Setup:** Select Positioned Sketch → Origin = Projection Point (select Part Origin) → Orientation = Parallel to Line (select Z-axis as Vertical).

**Rescue:** If an existing sketch has wrong orientation: `Right-click Sketch > Sketch Object > Change Sketch Support` → switch to Positioned and re-define references.

### "Cycle Detected" Error
**Root cause:** Bidirectional loop — Part follows Skeleton (via Paste Link), but Skeleton follows Part (via assembly face/edge constraints).

**Method A (Hard Delete):** Delete face/edge constraints in the assembly. Replace with Plane-to-Plane coincidence constraints.

**Method B (Isolation):** Open Skeleton and Part in *separate windows* with no assembly context open. Perform the Paste Link there — avoids the cycle at paste time.

**Re-lock position safely:** Use Coincidence Constraints between XY, YZ, and ZX planes only — never face references.

**Flipped orientation:** Toggle constraint from "Opposite" to "Same."

---

## Structure (As-Built)

Current assembly organization. Update this as the model evolves.

### Top-Level
```
QDD Master Assem (Top-down) A.1
├── Gearbox_Master_Assem A.1
│   ├── SKL_Skeleton A.1 (SKL_Gearbox.1)    ← master reference, FIXED
│   ├── gear_set A.1                          ← sun, planets, ring gears
│   ├── carrier_assem A.1
│   │   ├── carrier_bottom A.1
│   │   ├── carrier_top A.1
│   │   ├── cutting_bodies A.1                ← shared boolean cutter tool
│   │   └── skeleton_refs A.1                 ← pasted skeleton geometry
│   ├── housing_assem A.1
│   │   ├── housing_body A.1
│   │   ├── housing_lid A.1
│   │   ├── cutting_bodies A.1
│   │   ├── skeleton_ref A.1
│   │   └── 6805-2RS Ball Bearings (×2)
│   └── 6805-2RS Ball Bearings (×2)
├── MotorHousing A.1
│   ├── D6374_150kv A.1
│   ├── Motor_enclosure_cap A.1
│   └── Motor_enclosure_housing A.1
└── Engineering Connections
```

**Reference screenshots:** `docs/images/`
- `full-assembly-cross-section.png` — complete assembly stack, cross-sectioned
- `master-assembly-tree.png` — top-level tree with housing and motor visible
- `carrier-assembly-tree.png` — carrier sub-assembly with cutting_bodies and external refs
- `housing-lid-detail.png` — lid part showing external references from skeleton

### What the Skeleton Publishes
- Number of planets
- Gear sizes (pitch diameters)
- Center axis (for patterns)
- (add more as you build them)

### Key Relationship
Gear set and carrier align because they both reference the same source of truth (skeleton), not because one contains the other. They're parallel branches, both driven by skeleton.

---

*Last updated: Feb 18, 2026*

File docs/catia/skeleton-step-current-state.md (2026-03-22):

# Skeleton + STEP Integration — Current State of Knowledge

Written 2026-03-01. Purpose: separate confirmed facts from assumptions before planning.

---

## CONFIRMED FACTS

### Skeleton parameters (from assembly_dump.txt)

| Parameter | Current Value |
|---|---|
| `ring_pitch_diam` | 75mm |
| `ring_wall_thickness` | 10mm |
| `ring_gear_OD` | 101.25mm |
| `housing_ring_gear_bore` | 101.55mm |
| `planet_pitch_diam` | 27.55mm |
| `sun_pitch_diam` | 19.9mm |
| `planet_mid_path` | 23.725mm |
| `gear_module` | 2.5mm |
| `carrier_planet_clearance` | 1.25mm |
| `gearbox_housing_sandwich_fastener_diam` | 5.5mm |
| Sandwich fastener bolt circle radius | 45.625mm |

### Skeleton formulas that use gear_module (confirmed by Aaron)

- **Formula.71:** `ring_pitch_diam + 2*(1.25*gear_module + ring_wall_thickness)` → drives `ring_gear_OD`
- **Carrier cutout formula (external part):** `planet_pitch_diam + 2*gear_module + carrier_planet_clearance`

### STEP file geometry (from generate_step_aaron.py source code)

- Ring outer diameter = `2 × (TARGET_RING_DIAMETER_MM/2 + RING_WALL_MM)` = `2 × (37.5 + 10)` = **95mm** — this is in the code, not estimated
- Ring pitch reference diameter = 75mm
- `RING_WALL_MM = 10mm` in the script is measured **from pitch reference to OD** (not from tooth root to OD)
- Sun outer diameter ≈ 19.9mm — from script print output (previous run)
- Planet outer diameter ≈ 29.1mm — from script print output (previous run)
- Carrier radius ≈ 23.0mm — from script print output (previous run)

### Confirmed discrepancy

- Skeleton `ring_gear_OD` = 101.25mm
- STEP ring OD = 95mm
- **Difference: 6.25mm — the skeleton ring gear is currently 6.25mm larger than the STEP geometry**

### Formula.55 (inferred from math — high confidence)

`ring_gear_OD - ring_wall_thickness` = 101.25 - 10 = 91.25mm = 2 × 45.625mm (sandwich fastener radius from dump). The math matches exactly, so Formula.55 almost certainly drives the sandwich fastener bolt circle.

### Physical setup (from Aaron)

- The bolt through the ring gear circumference **is the sandwich fastener** — same pattern at 45.625mm radius, 5.5mm diameter
- Aaron's concern: without knowing where solid material ends and tooth profile begins, bolt placement could have unequal wall thickness on each side

---

## ASSUMPTIONS / UNKNOWNS

### Ring gear tooth geometry — NOT measured

- **Ring tooth root radius: unknown.** I estimated ~39–40mm (2–3mm beyond the 37.5mm pitch line) based on typical cycloidal proportions. This has NOT been measured from the STEP or calculated from the script.
- **Ring solid wall (root to OD): unknown.** I estimated ~7–8mm. Depends entirely on the tooth root radius above.
- **Ring tooth depth: unknown.** Depends on tooth root radius.

### Formula.17 — confirmed by Aaron

`(sun_pitch_diam + planet_pitch_diam)/2` **directly drives `planet_mid_path`.** It is not a free parameter — it is formula-derived from the pitch diameters using the involute carrier radius rule. Changing sun/planet diameters will silently update planet_mid_path to the wrong value for cycloidal gears.

### Sandwich fastener clearance — partially unknown

- Outer clearance after ring_gear_OD fix: 47.5 - 42.5 - 2.75 = **2.25mm** — this is a real calculation (confirmed geometry)
- Inner clearance (bolt to tooth root): **unknown** — depends on tooth root radius above

### Cycloidal gear parameter values — from previous script run

The sun OD (19.9mm), planet OD (29.1mm), and carrier radius (23.0mm) were printed by a previous script run and recorded in the integration doc. They have not been independently verified since. The values should be correct for the current script parameters but have not been re-confirmed.

---

## ALL CONFIRMED — Script run 002 results (2026-03-01)

| Value | Result | Notes |
|---|---|---|
| Ring tooth root radius | **37.500mm** | Exactly at pitch line — roots don't extend past it |
| Ring tooth depth | **1.531mm** | Shallow — tip to root |
| Ring solid wall | **10.000mm** | Full wall is solid material |
| Ring outer radius | 47.500mm | OD = 95mm ✓ |
| Carrier radius | **22.959mm** | Use this, not 23.0mm |
| Sun outer diameter | 19.898mm | ≈ 19.9mm ✓ |
| Planet outer diameter | 29.082mm | ≈ 29.1mm ✓ |

**Sandwich fastener — Formula.55 needs no changes.**
After ring_gear_OD fix to 95mm: bolt circle = (95-10)/2 = 42.5mm radius, exactly midpoint of ring wall.
Inner clearance (root to bolt edge): 42.5 - 37.5 - 2.75 = **2.25mm**
Outer clearance (OD to bolt edge): 47.5 - 42.5 - 2.75 = **2.25mm** — symmetric, acceptable for printed parts.

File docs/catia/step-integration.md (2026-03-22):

# CATIA STEP Integration

How to get pygeartrain STEP gear bodies into the skeleton-driven QDD assembly.

## Overview

The gear integration lives in a dedicated **product** (`gears`) with four sibling parts:

| Part | Role |
|---|---|
| `skel_ref` | Fixed reference — holds pasted skeleton planes, sketches, axes. All other parts mate to this. |
| `gear_set` | Parametric placeholder gears (simple pads). Drives downstream parts (carrier, etc.). |
| `gear_part_output_rev01` | Imported STEP from pygeartrain — real herringbone cycloidal tooth geometry. |
| `cutting/adding bodies` | Separate part for boolean operations (bearing bores, bolt holes). References skeleton only. |

**Architecture rules:**
- The master skeleton (`SKEL_Gearbox`) is the single source of truth
- Each part independently pulls skeleton publications via Paste Link — no cross-referencing between parts (unreliable in practice)
- Cutting bodies reference skeleton datums only, never a specific gear part — this makes them survive STEP swaps
- `skel_ref` is the fixed anchor; all parts constrain to it, not to each other

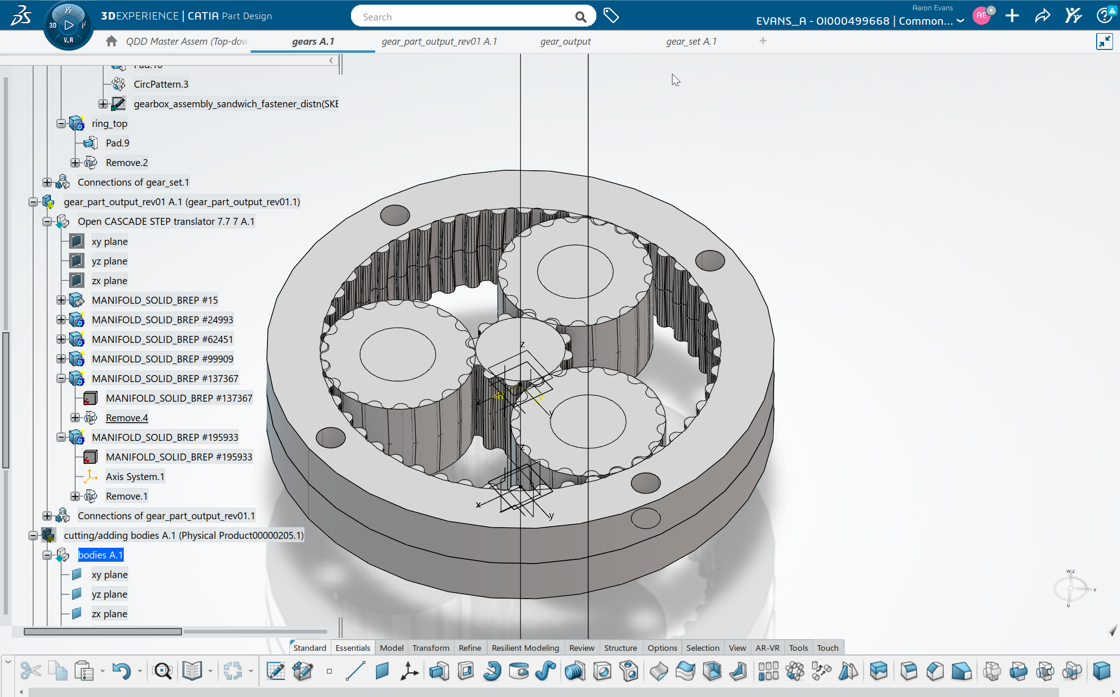
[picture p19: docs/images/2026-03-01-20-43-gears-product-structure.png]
Gears product structure


**Key files:**
- STEP generator: `pygeartrain/generate_step_aaron.py`
- Latest STEP output: `pygeartrain/step_output_aaron/` (run 002)
- Confirmed geometry values: `docs/catia/skeleton-step-current-state.md`
- Pipeline README: `pygeartrain/step_output_aaron/README.md`

---

## Step 0 — Skeleton Cleanup (prerequisite)

Skeleton was built for involute gears (module=2.5mm). New geometry is cycloidal — two parameter changes fix everything.

**Open SKEL_Gearbox in CATIA → parameter list (Tools > Parameters or formula editor).**

| Parameter | New value | Why |
|---|---|-----|
| `sun_pitch_diam` | **16.836mm** | Actual sun pitch diameter. Formula.8 and Formula.17 cascade everything else. |
| `gear_module` | **0mm** | Zeroes out module term in ring_gear_OD and carrier cutout. Safe — no formulas divide by it. |

`ring_pitch_diam` stays at 75mm — already correct.
`planet_pitch_diam` is driven by Formula.8 `(ring_pitch_diam - sun_pitch_diam)/2` — updates automatically.
`planet_mid_path` is driven by Formula.17 `(sun_pitch_diam + planet_pitch_diam)/2` — updates automatically.

### What will cascade (expect these — all correct)

| Parameter | Before | After | Formula |
|---|---|---|---|
| `planet_pitch_diam` | 27.5mm | **29.082mm** | Formula.8 |
| `planet_mid_path` | 23.75mm | **22.959mm** | Formula.17 |
| `ring_gear_OD` | 101.25mm | **95mm** | Formula.71 |
| `housing_ring_gear_bore` | 101.55mm | **95.3mm** | Formula.60 |
| `housing_width` | 115.25mm | **109mm** | Formula.32 |
| `lid_step_OD` | 101mm | **94.75mm** | Formula.66 |
| Sandwich fastener bolt circle | 91.25mm dia | **85mm dia** | Formula.55 |

**Check:** `ring_gear_OD` should read 95mm. `housing_ring_gear_bore` should read 95.3mm (matches STEP ring OD of 95mm + 0.3mm clearance).

### Carrier cutout formula (external part)

`planet_pitch_diam + 2*gear_module + carrier_planet_clearance` — gear_module is now 0, so this becomes `planet_pitch_diam + carrier_planet_clearance` = 29.082 + 1.25 = **30.332mm**. No action needed.

### Final parameter values after cleanup

| Parameter | Final value | How |
|---|---|-----|
| `sun_pitch_diam` | **16.836mm** | **You set this** |
| `gear_module` | **0mm** | **You set this** |
| `planet_pitch_diam` | 29.082mm | Auto — Formula.8 |
| `planet_mid_path` | 22.959mm | Auto — Formula.17 |
| `ring_gear_OD` | 95mm | Auto — Formula.71 |
| `housing_ring_gear_bore` | 95.3mm | Auto — Formula.60 |
| `housing_width` | 109mm | Auto — Formula.32 |
| `lid_step_OD` | 94.75mm | Auto — Formula.66 |

---

## Step 1 — Import STEP → gear_part_output

1. Open `gearbox_CAD.step` (run 002) — import as a **Part** (not Product/Assembly)
2. All bodies land in one shared coordinate system — rigid, nothing drifts
3. Save as native CATPart (`gear_part_output_rev01`)
4. Insert into the `gears` product as a sibling to `skel_ref` and `gear_set`
5. Bodies: MANIFOLD_SOLID_BREP entries (sun, planets, ring halves)

The `_CAD` file uses a `TopoDS_Compound` — all bodies share one origin, primary axis on Z.

**If STEP import creates an assembly:** Re-import and explicitly choose "Import as Part" / "As Result". The file is a compound (multi-body), not an assembly.

---

## Step 2 — Constrain to Skeleton

Each part in the `gears` product independently pulls skeleton publications via Paste Link into its own external references. Don't cross-reference between sibling parts — go directly to the master skeleton.

`gear_part_output` needs at minimum:
- `PUB_Gear_midplane`
- `PUB_z_axis`
- `PUB_planet_center_datum_axis`

Constrain `gear_part_output` to `skel_ref`:

| Constraint | From (gear_part_output) | To (skel_ref) | Purpose |
|---|---|---|---|
| Coincidence (axis) | Sun bore axis | `PUB_z_axis` | Concentric with gearbox axis |
| Coincidence (plane) | Ring split face at $z=0$ | `PUB_Gear_midplane` | Axial positioning |
| Fix rotation | Part X-axis or planet_0 direction | Skeleton X-axis | Prevent free spin |

The entire multi-body part locks in place. All internal geometry (planet positions, ring wall, tooth profiles) is already correct because it was built relative to the origin in CadQuery.

---

## Step 3 — Verify Fit

After constraining, check:

- [ ] Ring OD sits inside `housing_ring_gear_bore` (95.3mm bore, ring OD = 95mm → 0.15mm radial gap)
- [ ] Planets sit at the correct orbital radius — compare planet center distance against skeleton `planet_mid_path` (22.959mm)
- [ ] Gear midplane aligns with skeleton `Gear_midplane` datum
- [ ] No interference between planet tips and ring root / sun root (visual check in section view)
- [ ] Planet interference with carrier — `carrier_planet_clearance` (1.25mm) was designed for involute teeth; cycloidal have different tip profiles, may need adjustment

---

## Step 4 — Skeleton-Driven Cuts (later)

Operations live in the `cutting/adding bodies` part — a separate sibling in the `gears` product. This part is **not dependent on any specific gear part** — it references skeleton datums only.

- Use the **same sketches/profiles** that `gear_set` uses (referencing skeleton datums, not STEP faces)
- Bearing bores: sketch on `PUB_Gear_midplane`, pad through body using `PUB_planet_center_datum_axis`
- Bolt holes: reference `PUB_planet_bearings` sketch
- Boolean Remove the cutting bodies against STEP bodies in `gear_part_output`

**Key rule:** Every sketch and limit must reference a skeleton datum or the `outline` profiles — never a STEP face. This is what makes STEP swapping possible and cutting bodies reusable across revisions.

---

## Step 5 — STEP Swap (future runs)

When a new `gearbox_CAD.step` is generated (new run from pygeartrain):

1. In `gear_part_output`, locate the base STEP bodies
2. Replace/re-insert with new STEP file (save as new rev, e.g. `gear_part_output_rev02`)
3. Cutting bodies recompute automatically — they reference skeleton datums, not STEP faces
4. Check for broken references (should be none if Step 4 was done correctly)

Should be a ~5 minute operation per new STEP version.

---

## Step 6 — Manufacturing Export

For each gear body in `gear_output`:
- Extract body → individual STEP/STL for printing or machining
- Or use `_PRINT` files from pygeartrain directly if no skeleton-driven cuts were applied to that body

CadQuery export types:

| File | Purpose |
|---|---|
| `sun_PRINT.step/.stl`, `planet_N_PRINT.step/.stl`, `ring_top/bottom_PRINT.step/.stl` | Clean individual parts → slicer or manufacturer |
| `gearbox_CAD.step` | Multi-body part (all gears in one coordinate system) → CATIA |

---

## Open Questions (to test in CATIA)

- **Does CATIA allow "Replace" on a STEP-derived body?** If yes, Step 5 is trivial. If no: delete old bodies, insert new ones, cutting bodies recompute.
- **Circular pattern of planets:** `gear_set` uses `CircPattern.2` to pattern planet operations. Does this work when applied to STEP bodies via cutting bodies? Or does each planet need operations individually?
- **Boolean workflow:** How does the cutting/adding bodies part apply its operations to `gear_part_output`? Product-level boolean, or assembly-level cut? Need to test.

---

## What Not To Do

- **Don't reference STEP faces in operations** — any face picked directly from the STEP body will break when the STEP is swapped
- **Don't fuse gear_set and gear_part_output into one part** — keeps things clean and lets gear_set stay as pure parametric reference
- **Don't delete gear_set** — it's the parametric backbone, needed for interference checks and skeleton validation
- **Don't cross-reference external params between sibling parts** — each part pulls directly from the master skeleton. Cross-part references were unreliable in practice.

---

## What the Skeleton Still Drives

Even with real gear geometry imported, the skeleton controls:
- Carrier plate dimensions (top/bottom thickness, clearances)
- Housing bore, wall thickness, mounting layout
- Bearing seats (main bearing, planet bearings)
- Fastener patterns (sandwich bolts, planet pins)
- Overall packaging envelope

The gear STEP bodies don't replace the skeleton — they complement it with real tooth geometry.

---

## Troubleshooting

**STEP import looks wrong / no solid body:**
- Try importing with "As Result" rather than "As Specification" if available
- If compound import fails, import individual `_PRINT` files one at a time

**Gears don't align with skeleton:**
- Verify the part's origin matches the skeleton origin
- STEP files use mm units — confirm CATIA is set to mm

**Ring doesn't fit in housing:**
- Ring OD should be 95mm, housing bore 95.3mm
- If ring OD appears different, check that the script ran with `RING_WALL_MM = 10` and `TARGET_RING_DIAMETER_MM = 75`

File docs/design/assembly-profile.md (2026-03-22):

# Assembly Profile — QDD Planetary Gearbox

A living document that builds up a complete picture of the assembly over time. Updated as Aaron shares more info across sessions — small details here and there get consolidated here instead of scattered across discussion files.

**Last updated:** 2026-02-19

---

## Assembly Overview

A 5:1 planetary gearbox (FDM 3D-printed) that sits on top of a BLDC motor. The motor shaft passes through the housing base and connects to the sun gear. Output is through the carrier, which rotates on two main bearings.

**Key design properties:**
- Backdrivable (QDD = quasi-direct-drive)
- Target backlash ≤ 0.5°
- Gear module: 2.5mm (8/11/30 teeth on sun/planet/ring)
- Ratio: 4.75:1 (from pitch diameter ratios: 1 + 75/20)
- No post-processing — everything as-printed
- No seals — silicone grease applied manually
- Budget under $120 CAD
- Printer: Bambu P1S

---

## Parts & How They Fit Together

### Housing Body
- Cup shape — closed bottom, open top
- Motor bolts to the bottom face (gearbox sits on top of motor)
- Motor shaft passes through a clearance hole (`motor_shaft_clearance_hole = 18mm`) in the base
- Contains a cylindrical bore (~⌀95mm) where the ring gears slide in from the top
- Has a bearing pocket/shoulder for the **bottom main bearing** (6805-2RS, ⌀37mm OD)
  - Shoulder supports bearing axially: `main_bearing_shoulder_OD = 34.5mm`, `main_bearing_shoulder_ID = 27.4mm`
  - Bearing sits on a lip, spaced above the housing floor by `main_bearing_base_clearance = 1.5mm`
- M3 fasteners connect housing body to motor housing
- M5 sandwich fasteners (×4) clamp housing body + lid + ring gears together
- `Housing_base_thickness = 5mm`, `Housing_min_wall_thickness = 7mm`

### Lid
- Sits on top of the housing body
- Has a **step** that drops down into the housing bore — this does two things:
  1. Radially locates the lid concentric with the housing (self-centering)
  2. Presses down onto the ring gears, providing axial constraint
- Contains a bearing pocket for the **top main bearing** (6710-2RS, 50×62×6mm)
- Carrier output shaft pokes through the lid: `carrier_output_lid_stickout = 1.5mm`
- `housing_lid_thickness = 15.95mm`, `housing_lid_min_thickness = 7mm`
- Prints face-down (open side up) — bearing bore is built up layer by layer, good for roundness

### Ring Gears (×2 halves)
- Split at mid-height — each half has half the herringbone teeth
- Slide into the housing cylindrical bore from the top
- Lid presses down on them axially — radial fit just needs to locate concentrically, not retain
- Both halves must be identical OD for consistent mesh
- `ring_pitch_diam = 75mm`, `ring_wall_thickness = 10mm`
- `gear_height = 20mm` (both halves combined)

### Carrier (clamshell — 2 halves)
- Bottom half and top half bolted together by shoulder screws
- Shoulder screws do triple duty: planet pins + carrier fastener + carrier alignment
- No separate dowel pins or locating features — shoulder screws handle alignment
- Bottom half has a lip that catches the bottom main bearing OD (bearing OD interfaces with bottom carrier plate)
- Top half interfaces with the top main bearing via the lid
- Output shaft is part of the carrier: `carrier_output_OD = 25mm`, `carrier_output_shaft_length = 17.45mm`
- `carrier_diam = 70mm`, `carrier_plate_bottom_h = 10.95mm`, `carrier_plate_thickness = 4mm`
- `carrier_plate_min_thickness = 2mm` (min material above/below planet pocket)

### Planet Gears (×3)
- Herringbone teeth — self-centering axially, floating
- Each planet has a 685ZZ bearing (⌀14mm OD, ⌀5mm ID, 5mm wide) press-fit into its bore
- The bearing sits well inside the gear (20mm tall gear, 5mm wide bearing — no protrusion)
- Spaced 120° apart: `planet_spacing = 120deg`
- `planet_pitch_diam = 27.5mm`, `planet_mid_path = 23.75mm`
- `carrier_planet_clearance = 2mm` axial clearance — generous for FDM

### Planet Bearings (685ZZ × 3)
- Outer race press-fits into planet gear bore (gear is the rotating part)
- Inner race rides on shoulder screw (pin is stationary)
- `carrier_bearing_OD = 14mm`, `carrier_bearing_ID = 5mm`, `carrier_bearing_h = 5mm`
- Bearing shoulders in carrier: `planet_bearing_shoulder_OD = 12.4mm`, `planet_bearing_shoulder_ID = 6.6mm`

### Shoulder Screws (×3)
- Act as planet pins AND carrier clamshell fasteners
- Shoulder diameter = 5mm (bearing inner race rides on the shoulder)
- Threaded end clamps carrier halves together
- `carrier_planet_fastener_diam = 5mm`

### Sun Gear
- Press fit onto motor D-shaft (circle with flat)
- D-flat prevents rotation, FDM undersizing creates natural press fit
- `sun_pitch_diam = 20mm`
- Motor shaft diameter: TBD (needs measurement with calipers)

### Main Bearings
- **Bottom bearing:** 6805-2RS (ID 25mm, OD 37mm, height 6.95mm) — sits on housing shoulder, OD interfaces with bottom carrier plate
- **Top bearing:** 6710-2RS (50×62×6mm) — sits in lid, carrier top interfaces with it

---

## Assembly Order (Bottom → Top)

1. **Housing body** — base of everything
2. **Bottom main bearing** (6805-2RS) — drops into housing bore, sits on shoulder
3. **Bottom carrier half** — pushes down onto bearing OD, lip catches the outer race
4. **Planet gears** (with 685ZZ bearings pre-pressed in) — sit on carrier
5. **Sun gear** — press-fit onto motor shaft, meshes with planets
6. **Ring gear halves** — slide into housing cylindrical bore from top, mesh with planets
7. **Top carrier half** — placed on top, shoulder screws thread through planet bearings and clamp both carrier halves
8. **Top main bearing** (6805-2RS) — sits on carrier top / in lid pocket
9. **Lid** — step drops down onto ring gears, bearing pocket captures top bearing, sandwich fasteners clamp everything

---

## Axial Constraint Chain

What holds everything in place vertically:

- **Ring gears** rest on housing body (gravity + lid pressure from above)
- **Lid step** presses down on ring gears
- **Bottom main bearing** sits on housing shoulder
- **Carrier** sits on bottom bearing (lip catches ID), constrained from above by top bearing + lid
- **Planets** float axially — herringbone teeth self-center
- **Sandwich fasteners** (M5 × 4) clamp lid to housing body, compressing the whole stack
- **`carrier_lid_clearance = 2mm`** is the buffer in the axial stack — absorbs FDM tolerance accumulation

---

## Radial Constraint Chain

What keeps everything concentric:

- **Housing bore** locates ring gears and lid step concentrically
- **Main bearings** locate carrier concentric to housing (Datum B = bearing bore axis)
- **Carrier** locates planet pins at 120° spacing
- **Planet bearings** locate planets on pins
- **Ring gear bore** and planet mesh keep gear train aligned

---

## Key Design Decisions

| Decision | Rationale |
|---|---|
| Herringbone planets | Self-centering axially, more tolerant of radial misalignment than spur |
| Clamshell carrier | Allows planet assembly — gears and bearings trapped between two halves |
| Shoulder screws as pins | Simplifies BOM, dual-purpose (pin + fastener + alignment) |
| No post-processing | Prototype simplicity — everything as-printed, adjust offsets parametrically |
| Split ring gear | Enables herringbone teeth (can't insert through solid ring) |
| Skeleton-driven CAD | All dimensions flow from skeleton parameters — change one value, everything updates |
| Separate tolerance offsets | Nominal bearing dims stay pure; FDM offsets applied via formulas on specific features |

---

## CAD Strategy

- **Software:** 3DEXPERIENCE CATIA (student version)
- **Approach:** Skeleton-driven parametric modeling
  - Skeleton A.1 contains all master parameters and reference geometry
  - Individual parts reference skeleton dimensions via formulas/publications
  - Changing a skeleton parameter propagates to all parts
- **Current state:** Skeleton complete, parts modeled, tolerances being added
- **Known challenge:** Parameter organization is hard to navigate in V6 — using naming prefixes to group related params

---

## Manufacturing Notes

- **Printer:** Bambu P1S
- **Material:** TBD (likely PLA or PETG for prototype)
- **General FDM accuracy:** ±0.2mm
- **Bore undersizing:** ~0.1-0.2mm (holes print smaller than modeled)
- **Shaft oversizing:** slight (shafts print larger than modeled)
- **Print orientations:**
  - Housing: open top up
  - Lid: face-down (open side up)
  - Gears: flat
  - Carrier halves: side by side
- **No test prints yet** — calibration coupon planned before full build

---

## Open Items / TBD

- [ ] Measure motor shaft diameter with calipers (needed for sun gear bore)
- [ ] Calibration print to determine printer-specific offsets
- [ ] M3 heat-set insert dimensions for carrier (`carrier_heatsert_diam` and `carrier_heatsert_depth` currently 0)
- [ ] Verify ring gear housing bore dimension in CATIA — Formula.55 currently = `ring_pitch_diam + ring_wall_thickness`, may need correction
- [ ] Design table setup (after prototype validated)

---

*This document grows over time. When Aaron shares new info about the design, it gets consolidated here.*

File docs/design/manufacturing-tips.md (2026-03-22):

# Manufacturing Tips — QDD Gearbox

Practical tips, lessons learned, and design-for-manufacturing knowledge collected over the project. Useful for documentation, blog posts, and future reference.

**Last updated:** 2026-02-19

---

## Heat-Set Inserts (Brass, FDM)

### Pilot Hole Sizing
- Model the hole at the **insert's OD** (outer diameter from datasheet/package)
- FDM naturally prints holes ~0.1-0.2mm undersized, creating the right interference
- Do NOT use generic "recommended pilot hole" tables from Ruthex/McMaster — those assume injection-molded parts. FDM is different

### Hole Depth
- Make the hole **1.5× the insert length** to give displaced plastic somewhere to go
- Without this extra depth, melted plastic fills the insert's internal threads

| Insert | OD | Length | Pilot Hole Diameter | Pilot Hole Depth |
|---|-----|---|---|---|
| M3xL4xOD4.2 | 4.2mm | 4mm | 4.2mm | 6.0mm |
| M4xL4xOD5 | 5.0mm | 4mm | 5.0mm | 6.0mm |

### Installation
- Use a **non-tapered** soldering iron tip (tapered tips get stuck — the insert contracts around the taper as it cools, "Chinese finger trap" effect)
- Heat the insert for 10-15 seconds until ~90% seated
- **Plate-press technique:** Remove iron, flip part onto a flat metal surface (small sheet metal square works), press down gently. This seats the insert flush and consistent without needing precision
- Let cool 6-10 seconds before handling
- **TS100 iron tip kit** available specifically for heat-set inserts (in Aaron's inventory)

### Design Tips
- Use **minimum 4 perimeters** in slicer settings around insert holes (default is usually 2). More walls = better grip, less surface dimpling on the outside
- Optional: add a **45° chamfer** at the top of the hole to contain displaced material and guide the insert
- Insert holes should be vertical (parallel to print Z-axis) for best results — inserting into a side wall works but is harder to keep straight

---

## FDM Tolerancing (General)

### Dimensional Accuracy
- General accuracy: **±0.2mm**
- Bores print **undersized** by ~0.1-0.2mm (model oversized to compensate)
- Shafts print **slightly oversized** (model undersized to compensate)
- Large diameters have more absolute error — scale clearance with feature size

### Fit Strategy for FDM
- **Snug/transition fit:** Model bore +0.10mm over nominal
- **Press fit:** Model at nominal — FDM undersizing does the work
- **Clearance fit:** Model bore +0.2-0.3mm over nominal
- These are starting points — calibration print determines actual offsets for your printer

### Print Orientation Matters
- **Critical bores:** Orient vertically for best roundness (built up layer by layer)
- **Flat surfaces:** Best accuracy on the build plate (first layer)
- **Overhangs:** Avoid unsupported features on critical mating surfaces
- **Gear teeth:** Print flat for consistent tooth geometry across all teeth

### Calibration Print
Before committing to the full build, print a test coupon with representative features:
- Various bore diameters matching your design
- A boss/shaft feature
- Heat-set insert holes
- Measure everything with calipers, calculate offsets, apply to parametric model

---

## Fastener Clearance Holes (ISO 273)

Model clearance holes at the **close fit** value, not the bolt diameter:

| Bolt | Bolt Diameter | Close Fit Hole | Normal Fit Hole |
|---|---|---|---|
| M2 | 2.0mm | 2.4mm | 2.6mm |
| M2.5 | 2.5mm | 2.9mm | 3.1mm |
| M3 | 3.0mm | 3.4mm | 3.6mm |
| M4 | 4.0mm | 4.5mm | 4.8mm |
| M5 | 5.0mm | 5.5mm | 5.8mm |

For FDM: use close fit values. Holes will print slightly undersized, landing between close and nominal. Drill out if needed.

---

## Shoulder Bolts as Pins

Shoulder bolts can serve as both fastener and precision pin:
- The **shoulder** (unthreaded cylindrical section) acts as the bearing surface / pin
- The **threaded end** clamps parts together
- Shoulder diameter is precision-ground — much more accurate than 3D-printed features
- In the QDD gearbox: D5mm shoulder screws act as planet pins + carrier clamshell fasteners

---

*Add new tips as they come up — from test prints, assembly experience, research, etc.*

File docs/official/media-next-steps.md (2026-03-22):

# QDD Gearbox — Media Next Steps
> Checklist of photos, renders, graphs, and diagrams needed for website, blog post, and portfolio.
> Last updated: 2026-03-15.

---

## Photos To Take

| Shot | Description | Notes |
|---|---|---|
| Hero shot | Assembled Rev 00B, lid on, clean background | Good lighting, slightly angled top-down. This is the portfolio thumbnail. |
| Side profile | Assembled unit showing proportions and height | Neutral background, shows motor interface side |
| Backdriving demo | Hand turning the output shaft | Shows QDD transparency — the whole point of the project |
| Gear mesh close-up | Spur gear tooth engagement detail | Macro or close crop, shows print quality and mesh |
| Motor + gearbox | ODrive + motor + gearbox mounted together | Once integration is done — shows full actuator |
| Rev 00A vs 00B | Side-by-side comparison of both revisions | Highlights visible changes (spur vs herringbone, carrier redesign) |

## CAD Renders To Generate

Can use `/cad-render` skill with STL files in `prototypes/rev00b/prints/`.

| Render | Description | Files Needed |
|---|---|---|
| Exploded view | All Rev 00B components separated along assembly axis | All part STLs |
| Cross-section | Updated cut-away showing internal gear train | Full assembly STL or CATIA export |
| Transparent housing | Housing shown transparent, internals visible | Housing + internals STLs |
| Hero render | Clean product shot of assembled unit | Full assembly STL |
| Before/after | Rev 00A vs 00B renders side-by-side | Both revision assemblies |

## Graphs & Data Visualizations

| Visual | Description | Data Source | When |
|---|---|---|---|
| Backlash measurement | Angular backlash at output vs torque | Rev 00B testing | After Rev 00B test |
| Friction torque comparison | Rev 00A vs 00B friction torque bar chart | T-001 data + Rev 00B retest | After Rev 00B test |
| Efficiency curve | Efficiency vs speed (or vs load) | Motor testing with ODrive | After controls integration |
| Tolerance stack-up | Bearing interface stack-up diagram | Skeleton offset params | Can do now |
| Cost breakdown | BOM cost — pie or horizontal bar | BOM spreadsheet | Can do now |
| Trade study radar | Spider/radar chart of top 3 gear types | Trade study scores | Can do now (nice-to-have) |

## Diagrams

| Diagram | Description | When |
|---|---|---|
| Power flow schematic | Sun → planet → ring gear train schematic | Can do now |
| Skeleton parameter flow | Which skeleton params drive which parts | Can do now |
| Test dependency map | Component → Interface → Subsystem → System | Can do now |
| Assembly sequence | Step-by-step visual assembly guide | After Rev 00B finalized |
| Tolerance chain | Linear tolerance chain through bearing stack | With GD&T section |

## Available Photos (Rev 00B — completed)

Location: `prototypes/rev00b/photos/` (full-res) and `Portfolio/Website/src/qdd-gearbox/images/` (web-optimized)

| File | Description | On Website |
|---|---|---|
| `rev00b-3d-printing.jpg` | Parts on Bambu P1S print bed | Yes |
| `rev00b-parts-laid-out.jpg` | All parts laid out with bearings and hardware | Yes |
| `rev00b-parts-laid-out-no-body.jpg` | Parts laid out, housing body not in view | No (backup) |
| `rev00b-sun-planets-ring-bearings-installed.jpg` | Ring gear with planets and sun, bearings installed | Yes |
| `rev00b-lower-carrier-planets-sun-installed.jpg` | Lower carrier with gear train installed, top-down | Yes |
| `rev00b-lid-off-rest-installed.jpg` | Assembled gearbox with lid removed | Yes |
| `rev00b-testing-with-claude-code.jpg` | Test bench setup with laptop and ODrive | Yes |

## Available Photos (Documentation)

Location: `docs/images/`

| File | Description |
|---|---|
| `rev00a-cross-section.png` | Rev 00A CATIA cross-section (from dropbox) |
| `full-assembly-cross-section.png` | Full assembly cross-section render |
| Various CATIA screenshots | Assembly trees, detail views |

## Priority Order

1. **Hero shot** — needed for portfolio thumbnail, LinkedIn, OG image
2. **Cost breakdown** + **tolerance stack-up** — can generate now, adds substance
3. **CAD renders** — exploded view and cross-section add polish
4. **Backdriving demo** — the money shot for QDD, ideally a short video/GIF
5. **Graphs** — after Rev 00B quantitative testing

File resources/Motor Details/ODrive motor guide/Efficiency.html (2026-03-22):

| A | | B | C | D | E | F | G | H | I | J | K | L | M | N | O | P | Q
1 | | | Speed Constant (Kv) | Max Current* | Resistance | no load | | loss ratio | Optimal ratio | Optimal gearing | efficiency | Optimal speed at rated current | | | I at V
2 | (feilds highlighted in blue are inputs) | | rpm/v | A | mOhm | A | V | A/V | A/V | Ncm/krpm | | V | rpm | W | 24 | 36 | 48 | V
3 | Turnigy Aerodrive SK3 - 4250-350kv | | 350 | 50 | | | | #DIV/0! | #DIV/0! | #DIV/0! | #DIV/0! | #DIV/0! | #DIV/0! | #DIV/0! | #DIV/0! | #DIV/0! | #DIV/0!
4 | Turnigy Aerodrive SK3 - 5065-275kv | | 275 | 60 | | | | #DIV/0! | #DIV/0! | #DIV/0! | #DIV/0! | #DIV/0! | #DIV/0! | #DIV/0! | #DIV/0! | #DIV/0! | #DIV/0!
5 | ODrive Robotics D5065 - 270kv | | 270 | 65 | 39 | | | #DIV/0! | #DIV/0! | #DIV/0! | #DIV/0! | #DIV/0! | #DIV/0! | #DIV/0! | #DIV/0! | #DIV/0! | #DIV/0!
6 | ODrive Robotics D6374 - 150kv | | 150 | 70 | 39 | | | #DIV/0! | #DIV/0! | #DIV/0! | #DIV/0! | #DIV/0! | #DIV/0! | #DIV/0! | #DIV/0! | #DIV/0! | #DIV/0!
7 | Turnigy Aerodrive SK3 - 6374-149kv | | 149 | 68 | | | | #DIV/0! | #DIV/0! | #DIV/0! | #DIV/0! | #DIV/0! | #DIV/0! | #DIV/0! | #DIV/0! | #DIV/0! | #DIV/0!
8 | KEDA 63-64 190KV | | 190 | 50 | | | | #DIV/0! | #DIV/0! | #DIV/0! | #DIV/0! | #DIV/0! | #DIV/0! | #DIV/0! | #DIV/0! | #DIV/0! | #DIV/0!
9 | 9235-100KV Turnigy Multistar | | 100 | 57 | | | | #DIV/0! | #DIV/0! | #DIV/0! | #DIV/0! | #DIV/0! | #DIV/0! | #DIV/0! | #DIV/0! | #DIV/0! | #DIV/0!
10 | Hoverboard Hub-motor | | 16 | 25 | | | | #DIV/0! | #DIV/0! | #DIV/0! | #DIV/0! | #DIV/0! | #DIV/0! | #DIV/0! | #DIV/0! | #DIV/0! | #DIV/0!

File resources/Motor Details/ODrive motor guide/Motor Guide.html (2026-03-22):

| A | | B | C | D | E | F | G | H | I | J | K | L | M | N | O | P | Q | R | S | T | U | V
1 | Copy this spreadsheet to customize your analysis! 📚📐📏 | | Speed Constant (Kv) | Max Current* | Max voltage | Phase Resistance | Price (qty 1pc) | Mass | Link | Torque | No-load speed | | Power at base speed | Motor size constant (Km) (https://en.wikipedia.org/wiki/Motor_constants) | | Force | Linear Velocity | Linear Acceleration | Time to base speed | Distance to base speed | Base speed kinetic energy | Encoder freq. (base speed)
2 | (fields highlighted in blue are inputs) | | rpm/V | A | V | mOhm | USD | g | | Nm | RPM | Rad/s | W | Nm/sqrt(W) | | N | m/s | m/s^2 | ms | mm | J | kHz
3 | ODrive Robotics D5065 - 270kv | | 270 | 65 | 32 | 39 | 89 | 420 | https://odriverobotics.com/shop/odrive-custom-motor-d5065 | 1.99 | 8640 | 904.78 | 1801 | 0.13 | | 208.49 | 8.64 | 69.57 | 124.18 | 536.47 | 70.92 | 294.91
4 | ODrive Robotics D6374 - 150kv | | 150 | 70 | 48 | 39 | 119 | 890 | https://odriverobotics.com/shop/odrive-custom-motor-d6374-150kv | 3.86 | 5760 | 603.19 | 2328 | 0.23 | | 404.15 | 5.76 | 134.87 | 42.71 | 123.00 | 31.52 | 196.61
5 | ODrive Robotics D5312 - 330kv | | 330 | 50 | 30 | 37 | 59 | 230 | https://odriverobotics.com/shop/dual-shaft-motor-d5212s-300kv | 1.25 | 9900 | 1,036.73 | 1299 | 0.11 | | 131.22 | 9.90 | 43.79 | 226.09 | 1,119.14 | 93.11 | 337.92
6 | ODrive Robotics M8325s - 100kv | | 100 | 60 | 60 | 24 | 149 | 841 | https://shop.odriverobotics.com/ | 4.96 | 3840 | 402.12 | 1995 | 0.44 | | 519.62 | 3.84 | 173.40 | 22.15 | 42.52 | 14.01 | 131.07
7 | Tarot 4008 330kv | | 330 | 25 | 24 | | 32 | 80 | https://www.aliexpress.com/item/F17601-Tarot-4008-Martin-RC-Brushess-Motor-TL2955-RC-Quadcopter-Motor-for-Quadcopter-Multicopter-Drone/32697306634.html | 0.63 | 7920 | 829.38 | 520 | | | 65.61 | 7.92 | 21.89 | 361.74 | 1,432.50 | 59.59 | 270.34
8 | Turnigy Aerodrive SK3 - 4250-350kv | | 350 | 50 | 20 | | 36 | 266 | https://hobbyking.com/en_us/turnigy-aerodrive-sk3-4250-350kv-brushless-outrunner-motor.html | 1.18 | 7000 | 733.04 | 866 | | | 123.72 | 7.00 | 41.29 | 169.55 | 593.42 | 46.55 | 238.93
9 | Turnigy Aerodrive SK3 - 5065-275kv | | 275 | 60 | 40 | | 66 | 530 | https://hobbyking.com/en_us/turnigy-aerodrive-sk3-5065-275kv-brushless-outrunner-motor.html | 1.80 | 10560 | 1,105.84 | 1995 | | | 188.95 | 10.56 | 63.05 | 167.47 | 884.26 | 105.94 | 360.45
10 | KEDA 63-64 190KV | | 190 | 50 | 40 | | 49 | 670 | https://hobbyking.com/en_us/kd-53-30-high-voltage-brushless-outrunner-190kv.html | 2.18 | 7296 | 764.04 | 1663 | | | 227.90 | 7.30 | 76.05 | 95.93 | 349.97 | 50.57 | 249.04
11 | Turnigy Aerodrive SK3 - 6374-149kv | | 149 | 68 | 48 | | 90 | 840 | https://hobbyking.com/en_us/turnigy-aerodrive-sk3-6374-149kv-brushless-outrunner-motor.html | 3.77 | 5722 | 599.16 | 2261 | | | 395.23 | 5.72 | 131.89 | 43.38 | 124.10 | 31.10 | 195.30
12 | 9235-100KV Turnigy Multistar | | 100 | 57 | 48 | | 103 | 674 | https://hobbyking.com/en_us/9235-100kv-turnigy-multistar-brushless-multi-rotor-motor.html | 4.71 | 3840 | 402.12 | 1896 | | | 493.63 | 3.84 | 164.73 | 23.31 | 44.76 | 14.01 | 131.07
13 | Hoverboard Hub-motor | | 16 | 25 | 48 | | 40 | a lot | https://www.ebay.com/sch/i.html?_nkw=hoverboard+replacement+wheel | 12.92 | 614 | 64.34 | 831 | | | 1,353.16 | 0.61 | 451.56 | 1.36 | 0.42 | 0.36 | 20.97
14
15 | | | | *Note that torque and current ratings are with Extremely good forced air cooling
16 | | | | See Torque derating curve
17 | Parameter | | Value
18 | Bus voltage | | 48 | V
19 | Max modulation | | 0.8
20 | Load mass | | 1.9 | kg
21 | Rotor inertia | | 1.00E-04 | kg m^2
22 | Pulley circumference or screw pitch | | 60 | mm/rev
23 | Radius | | 0.009549296586 | m/rad
24 | Reflected inertia | | 1.10 | kg
25 | Peak brake power | | 1200 | W
26 | Brake resistor resistance | | 1.92 | ohm
27
28 | Conversion constants
29 | I by kv to Nm | | 8.269933431
30
31 | Encoder
32 | Encoder resolution | | 2048 | ppr
33 | Linear resolution | | 7.32 | um
34 | Max speed | | 15000 | RPM
35
36
37 | There are more tabs!
38
39
40
41
42
43
44
45
46
47
48
49
50
51
52
53
54
55

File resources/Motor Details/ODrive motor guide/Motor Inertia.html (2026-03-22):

| A | B | C | D | E | F | G | H | I | J | K | L | M | N | O
1 | | Rotor mass | Rotor diameter | Shaft length | Shaft diameter | Shaft density | Shaft mass | Shaft MoI | End Face thickness | End face density | End face mass | End Face MoI | Rotor casing mass | Rotor casing MoI | Total MoI
2 | | g | mm | mm | mm | kg/m^3 | g | kg*m^2 | mm | kg/m^3 | g | kg*m^2 | g | kg*m^2 | kg*m^2
3
4 | Red 5065 | 190 | 50 | 83 | 8 | 7850 | 32.7504751 | 5.24E-07 | 7.5 | 1350 | 19.88039101 | 6.21E-06 | 137.3691339 | 8.59E-05 | 9.26E-05

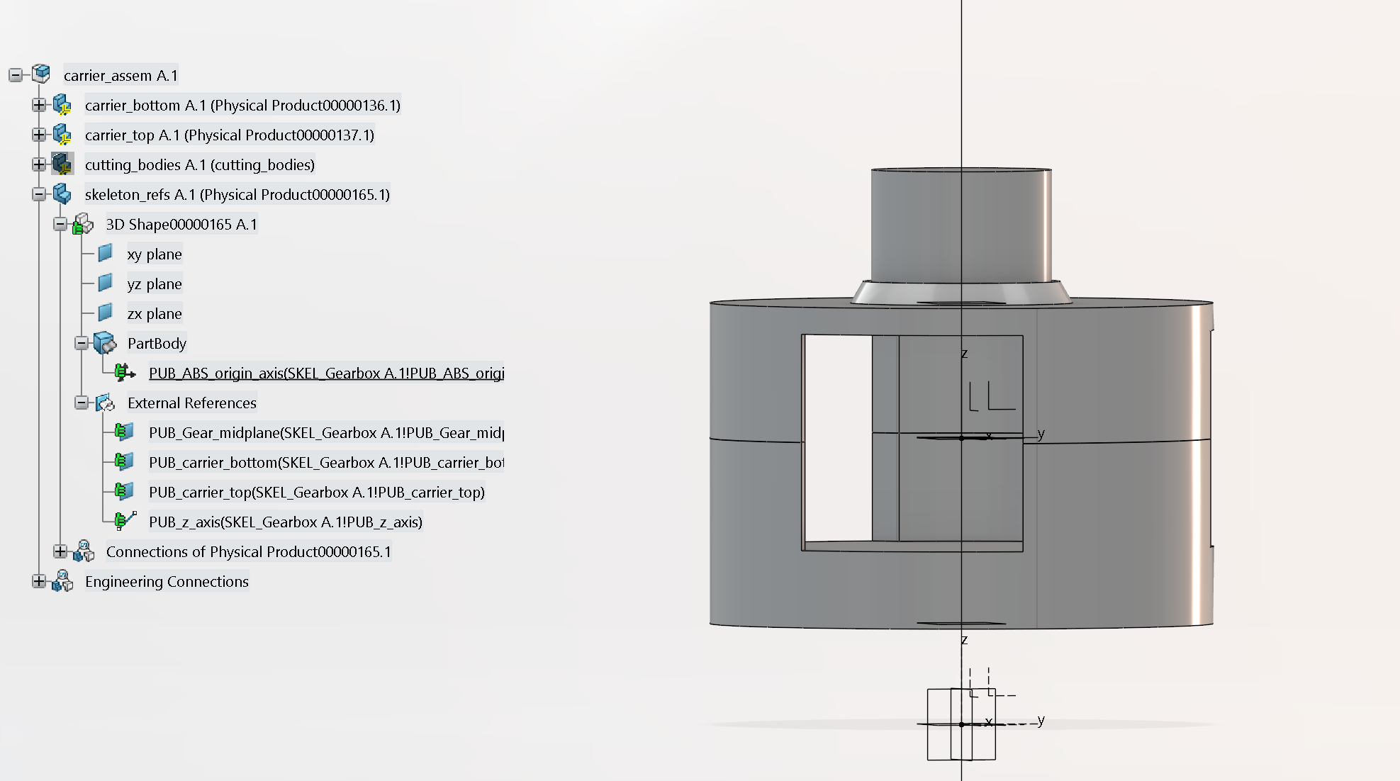
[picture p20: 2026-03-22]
docs/images/carrier-assembly-tree.png

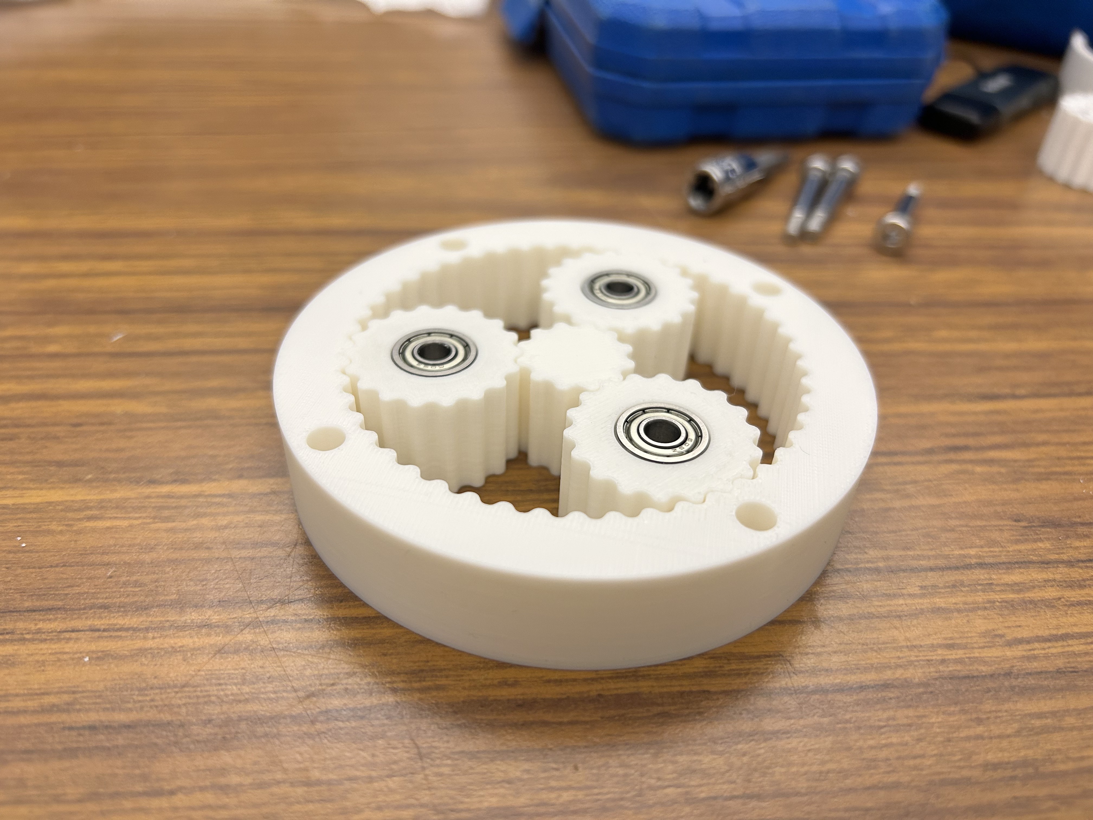
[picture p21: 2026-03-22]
prototypes/rev00b/photos/rev00b-sun-planets-ring-bearings-installed.jpg

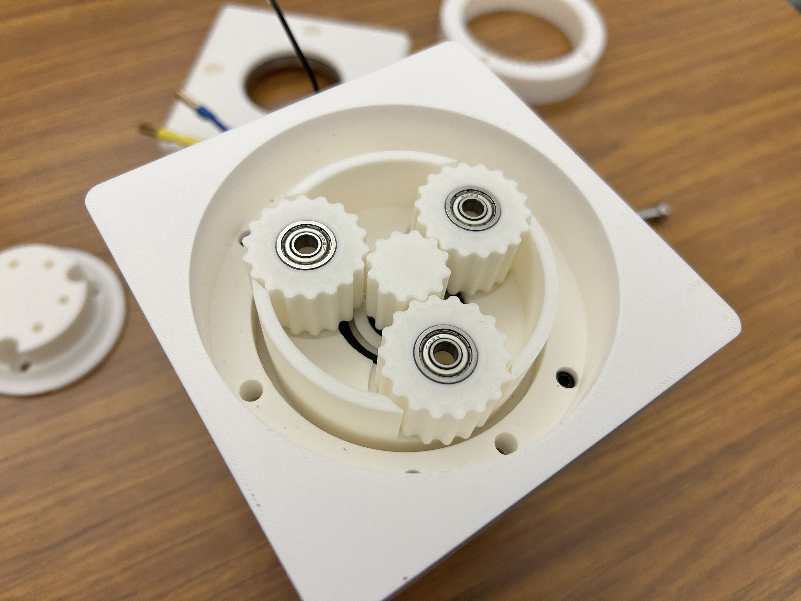
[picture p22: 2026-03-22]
prototypes/rev00b/photos/rev00b-lower-carrier-planets-sun-installed.jpg

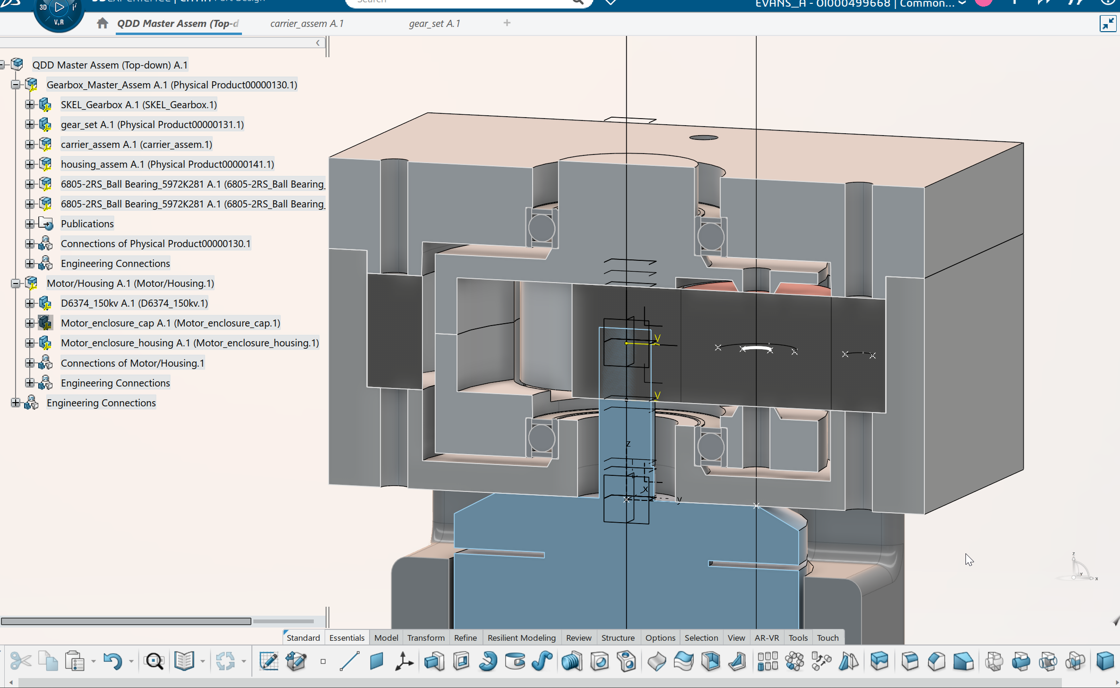
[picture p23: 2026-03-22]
docs/images/master-assembly-tree.png

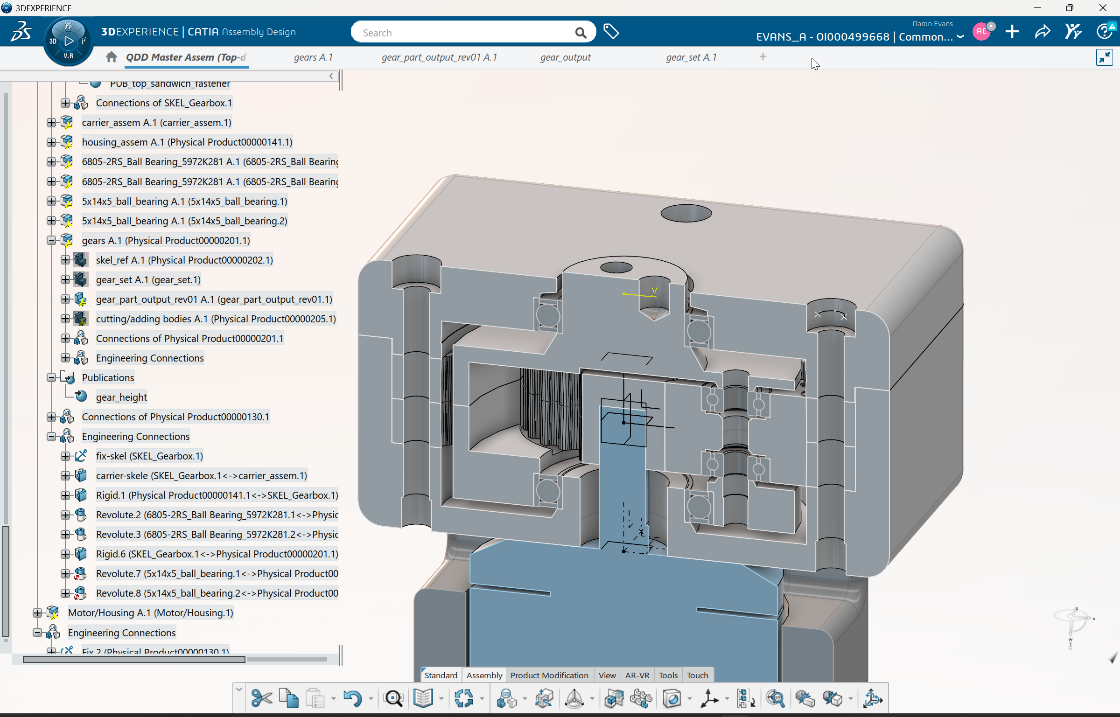
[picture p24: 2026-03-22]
docs/images/2026-03-01-21-19-master-assembly-with-gears.png

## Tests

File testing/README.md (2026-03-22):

# Testing — QDD Actuator

## Tracking Hub

**`qdd-rtm.xlsx`** — Requirements Traceability Matrix. This is the single source of truth for:
- All 13 design requirements (status, verification method, coverage)
- Traceability matrix (which tests verify which requirements)
- Test log (all 19 tests, status, results, acceptance criteria)
- Unknowns register (U-01 through U-10)
- Health log (degradation tracking over time)

## Reading Order

If you're starting from scratch, read in this order:

1. **`learn/motor-physics-primer.md`** — First-principles physics: current, torque, speed, heat, and how they connect. Start here if the equations don't make sense yet.
2. **`learn/campaign-walkthrough.md`** — What each test does and why, explained intuitively. Connects physics to the specific tests.
3. **`methodology/testing-fundamentals.md`** — How to think about testing: requirements traceability, unknowns, prioritization, test levels. Also has the variables/nomenclature table.
4. **`campaign/test-campaign-rev00b.md`** — The actual test procedures. Step-by-step instructions for each phase.
5. **`qdd-rtm.xlsx`** — Track progress, results, and traceability as you run tests.

## Folder Structure

```
testing/
├── qdd-rtm.xlsx           ★ tracking hub — requirements, tests, traceability
├── learn/                 "understand before you test"
│   ├── motor-physics-primer.md    — physics fundamentals
│   └── campaign-walkthrough.md    — intuitive test explanations
├── methodology/           "how to think about testing"
│   └── testing-fundamentals.md    — framework, variables table
├── campaign/              "the actual tests"
│   └── test-campaign-rev00b.md    — procedures (Phase 0–5)
├── hardware/              "physical test setup"
│   ├── test-bench-design.md       — portable bench design
│   └── dyno-smart-trainer.md      — CycleOps H2 as budget dyno
├── data/                  raw test results (CSVs, logs)
└── _archive/              superseded docs
    └── test-tracker-pre-rtm.md    — old markdown tracker (pre-RTM)
```

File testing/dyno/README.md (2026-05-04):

# Smart Trainer Dynamometer — CycleOps Hammer H2

> Using a borrowed CycleOps (Saris) Hammer H2 direct-drive smart trainer as a budget dynamometer for QDD actuator testing.

**Folder boundary:** this file is the hardware/test-concept reference: trainer limits, mechanical interface, adapter notes, and how trainer readings should be interpreted. The executable BLE capture tool lives in `testing/dyno/ble-capture/`.

---

## Why This Works

A direct-drive smart trainer is fundamentally a controllable brake with a calibrated power meter. It gives you something you don't otherwise have: **an independent torque measurement that doesn't depend on $K_t$**.

Right now, every torque number in the test campaign comes from $\tau = K_t \cdot I_q$ — which means if $K_t$ is wrong, everything downstream is wrong, and T-009 can only sanity-check $K_t$, not verify it (see testing-fundamentals.md). A trainer dyno closes that loop by measuring output torque directly.

---

## H2 Specifications (Relevant to Dyno Use)

| Parameter | Value | Notes |
|---|---|---|
| Power accuracy | ±2% | PowerTap-derived measurement |
| Max power | 2000 W @ 40 kph | More than enough for QDD |
| Resistance type | Electromagnetic | Fast response, controllable |
| Flywheel | 9 kg (20 lb) | Adds inertia — affects transient tests |
| Protocols | ANT+ FE-C, BLE Cycling Power Service, proprietary BLE resistance control | Matches local H2 tooling |
| Cadence broadcast | Integrated | No external sensor needed |
| Cassette compatibility | Shimano/SRAM 8–11 speed HG spline | Standard HG freehub body |
| Power supply | 110–240 V AC (mains required) | |
| Control modes | ERG (constant power), SIM (grade simulation) | ERG mode = constant load setpoints |

**Data update rate:** ANT+ power profile is typically ~4 Hz. The local BLE CPS path on this H2 is about `~1.1 Hz`. Both are fine for steady-state measurements but too slow for transient dynamics (step response, cogging). For transients, continue using motor-controller telemetry.

---

## What This Enables

| Test | Without Trainer | With Trainer |
|---|---|---|
| **$K_t$ verification (T-009)** | Indirect sanity check only — can't confirm actual value | Direct: apply known torque via trainer resistance, read $I_q$, solve $K_t = \tau / I_q$ |
| **Efficiency (η)** | $P_{in} = V \cdot I$ is known, but $P_{out}$ requires trusting $K_t$ | $\eta = P_{trainer} / P_{electrical}$ — independent measurement on both sides |
| **Friction torque ($\tau_f$)** | Backdrive by hand, estimate from $I_q$ | Trainer drives the gearbox backwards at known torque — directly measures friction |
| **Torque capacity** | Load until something breaks, trust $K_t$ for the number | Calibrated torque at failure point |
| **Continuous torque / thermal** | Run at commanded $I_q$, trust $K_t$ for load | Verified load via trainer power reading |

**What the trainer does NOT help with** (continue using ODrive data):
- Step response / transient dynamics (trainer data too slow)
- Cogging profile (need position-resolved $I_q$ at 8 kHz)
- Backlash measurement (need encoder counts, not power)
- High-speed testing >200 RPM (outside trainer's accurate range — see limitations)

---

## Mechanical Interface — The Adapter

### The Problem

The QDD gearbox output shaft needs to couple to the H2's Shimano HG freehub body. These are completely different interfaces.

### Shimano HG Freehub Spline Profile

The HG freehub is the industry standard cassette interface. Key characteristics:

| Feature | Value |
|---|---|
| Spline count | 9 splines + 1 wide key slot |
| Approximate OD across splines | ~34–35 mm |
| Body length (8/9/10-speed) | 34.9 mm |
| Smallest compatible cog | 11T |
| Spline profile | Shallow, parallel-sided, non-involute |

> **Shimano does not publish exact spline geometry.** The best approach is to **measure the actual freehub body on the H2** with calipers, or find/download a community HG spline CAD model (GrabCAD, Thingiverse — multiple exist) and verify against the physical part.

### Adapter Concept

```
QDD Output Shaft ──→ [ADAPTER] ──→ H2 Freehub Splines
     (your design)     (new part)     (standard HG interface)
```

The adapter needs:

1. **Input side (QDD):** Matches your gearbox output shaft geometry — whatever the current output interface is (D-shaft, keyed shaft, bolt pattern, etc.)
2. **Output side (trainer):** Female HG spline profile that slides onto the freehub body, same as a cassette cog
3. **Retention:** The freehub has a threaded end for a cassette lockring — you can use a standard lockring to hold the adapter in place
4. **Concentricity:** Both interfaces must be concentric to avoid runout and bearing side-loads

### Design Considerations

| Consideration | Notes |
|---|---|
| **Material** | 3D print is likely fine at 16 Nm — HG splines are shallow and the contact area is large. Print in PLA+ or nylon. If splines deform under load, machine from aluminum. |
| **Fit tolerance** | HG splines have a loose fit by design (cassette cogs slide on by hand). This is fine — torque is transmitted through the spline faces, not interference fit. |
| **Axial retention** | Use the existing cassette lockring (standard tool: FR-5.2 or similar). Thread onto freehub end, clamps adapter axially. |
| **Length** | Keep adapter short — you only need one "cog" worth of engagement (~3–5 mm spline contact minimum). Longer = more contact area but more overhang from gearbox. |
| **Alignment** | The trainer sits on the floor. The gearbox needs to be at the same height and axially aligned. You'll need some kind of mounting bracket or stand — even a simple plywood jig. |
| **Freehub ratchet direction** | The freehub has a one-way clutch (freewheel). It only transmits torque in one direction (forward pedaling). This means you can only load the gearbox in one rotation direction via the trainer's resistance. To test both directions, you'd need to reverse the setup or accept single-direction testing. |

### Steps to Build

1. **Measure the freehub body** — calipers on the actual H2. Get: OD across splines, root diameter between splines, key slot width, body length. Alternatively, pull a cassette cog off a bike and use that as your template.
2. **Measure QDD output** — whatever your current output shaft/interface is.
3. **CAD the adapter** — disc with female HG splines (ID) and QDD shaft interface (center bore or bolt pattern).
4. **Print and test fit** — slide onto freehub, check for slop, check lockring threads.
5. **Iterate** — if splines are too tight/loose, adjust by 0.1 mm and reprint.

> **Shortcut:** Pull an old cassette cog (any single cog from an 8–11 speed cassette) and use it as a known-good spline reference. Bore out the center to accept your output shaft. This skips the spline modeling entirely.

---

## Data Acquisition

### Option A: Cycling App + ANT+ Dongle (Simplest)

- Use any ANT+ USB dongle on a laptop
- Software: Zwift, TrainerRoad, or free options like GoldenCheetah
- Logs power (W), cadence (RPM) at ~1 Hz
- Good enough for steady-state efficiency sweeps

### Option B: ANT+ Python Library (Best for Automation)

- `openant` or `python-ant` library to read ANT+ data directly
- Sync with ODrive Python logging — timestamp both streams
- Get power and cadence from trainer + $I_q$, $\omega$, $\theta$ from ODrive in one script
- This is the ideal setup — single Python script runs both instruments

### Option C: Bluetooth CPS + Proprietary Control (Alternative)

- `bleak` Python library for BLE
- Cycling Power Service exposes power, torque, and wheel revolution data
- Resistance control appears to use a Saris proprietary BLE characteristic
- Can programmatically set trainer resistance from Python — fully automated test sweeps

### Recommended Approach

Option B or C — whichever protocol is easier to get working. The key advantage is **synchronized logging**: one Python script that simultaneously:
1. Commands motor current via ODrive
2. Reads $I_q$, $\omega$, $V_{bus}$ from ODrive
3. Reads power and cadence from trainer
4. Logs everything to a single CSV with aligned timestamps

---

## Test Procedures (Trainer-Based)

### Steady-State Efficiency Sweep

1. Set trainer to ERG mode at a target power (e.g., 10 W)
2. Command motor to constant velocity via ODrive
3. Wait for steady state (~5 s)
4. Log: ODrive $I_q$, $V_{bus}$, $\omega$ and trainer power, cadence for 10 s
5. $\eta = P_{trainer} / (V_{bus} \cdot I_q)$
6. Repeat at 10, 20, 30, 50, 75, 100 W (or whatever the gearbox can handle)
7. Plot $\eta$ vs load — this is the efficiency curve

### $K_t$ Calibration

1. Set trainer to ERG mode at a known power setpoint
2. Command motor at constant speed — trainer provides the resistive load
3. Compute trainer torque: $\tau_{trainer} = P_{trainer} / \omega_{output}$
4. Read $I_q$ from ODrive
5. $K_t = \tau_{trainer} / (I_q \cdot N \cdot \eta_{est})$ — iterate if needed, or test motor alone (no gearbox) for cleaner measurement
6. Compare to theoretical $K_t = 0.0551$ Nm/A

> **Cleaner $K_t$ calibration:** Remove the gearbox, couple motor shaft directly to trainer. Then $K_t = \tau_{trainer} / I_q$ with no gearbox losses in the loop. This requires a second adapter (motor shaft → freehub) but gives the cleanest number.

### Friction Torque (Backdriving)

1. Disconnect motor power (ODrive idle or disabled)
2. Use trainer in SIM mode to slowly drive the gearbox backwards
3. Read trainer power at the speed where the gearbox just barely turns
4. $\tau_f = P_{trainer} / \omega$ at that threshold
5. Sweep across several speeds to get the $\tau_f = \tau_c + b\omega$ curve

> **Note:** The freehub ratchet may complicate this — it freewheels in one direction. You may need to flip which device is driving vs. resisting, or accept testing friction in one direction only.

### Torque Capacity / Stall Test

1. Lock gearbox output (clamp adapter or use trainer at max resistance)
2. Slowly ramp motor current via ODrive
3. Monitor trainer torque (or use the stall condition where speed = 0 and $\tau = K_t \cdot I_q$)
4. Record max torque before: structural failure, gear skip, or current limit

---

## Limitations & Watch-Outs

| Issue | Impact | Mitigation |
|---|---|---|
| **Freehub is one-way** | Can only resist torque in one direction | Test both directions by swapping which device drives |
| **4 Hz power data** | Too slow for transient tests | Use for steady-state only; ODrive data for dynamics |
| **±2% accuracy** | At 10 W that's ±0.2 W — fine. At 1 W it's ±0.02 W — might hit noise floor | Test at higher power levels for better accuracy |
| **Speed range** | Trainer designed for 60–100 RPM cycling cadence | QDD at 600 RPM output is outside normal range — stay below ~200 RPM for reliable trainer data |
| **Flywheel inertia** | 9 kg flywheel smooths out torque ripple | Good for steady-state, masks cogging. Not a problem — cogging is measured with ODrive anyway |
| **Not the gearbox output RPM** | Trainer reads its own internal cadence, not your shaft speed | Use ODrive encoder for speed; trainer for torque/power only |
| **Mounting alignment** | Gearbox + trainer must be coaxial | Build a jig — even rough alignment is fine if adapter has some float |

---

## Bill of Materials (Adapter)

| Item | Source | Est. Cost |
|---|---|---|
| 3D printed adapter (PLA+/nylon) | Print | ~$1 material |
| Cassette lockring (Shimano compatible) | Bike shop / Amazon | ~$5 |
| Lockring tool (FR-5.2 or equivalent) | Bike shop / Amazon | ~$10 (or borrow) |
| ANT+ USB dongle (if using Option B) | Amazon | ~$25 |
| Mounting jig materials (plywood, bolts) | Hardware store | ~$10 |
| **Total** | | **~$50 or less** |

> **Shortcut option:** Scavenge a single cog from an old cassette (free if your friend has one), bore out the center, and bolt/epoxy to your output shaft adapter. Total cost: $0 + a lockring.

---

## Relationship to Test Campaign

This dyno setup augments the existing test campaign (test-campaign-rev00b.md) but doesn't replace it:

| Phase | Role of Trainer |
|---|---|
| **Phase 0 (motor baseline)** | Optional — could do $K_t$ calibration here instead of T-009 sanity check |
| **Phase 1 (gearbox assembly)** | Not needed — these are fit/function checks |
| **Phase 2 (gearbox quantitative)** | **Primary use** — efficiency sweeps, friction measurement, torque capacity with calibrated load |
| **Phase 3 (controls)** | Not needed for step response / Bode (too slow). Could verify impedance controller output torque at steady state |
| **Phase 4 (endurance)** | Could provide sustained calibrated load for extended run tests |

---

## Next Steps

- [ ] Confirm access to the H2 — when can you borrow it?
- [ ] Measure the freehub body dimensions (calipers on the actual unit)
- [ ] Decide on adapter approach: CAD splines from scratch vs. repurpose a cassette cog
- [ ] Prototype adapter and test fit
- [ ] Set up data acquisition (ANT+ or BLE Python script)
- [ ] Run first calibration test: motor-only $K_t$ verification

---

## Sources

- [CycleOps H2 In-Depth Review — DC Rainmaker](https://www.dcrainmaker.com/2019/01/cycleops-h2-hammer-2-trainer-in-depth-review.html)
- [Saris Direct Drive Shimano/SRAM Freehub](https://saris.com/products/direct-drive-shimano-sram-trainer-freehub)
- [Shimano Cassette Bodies — Sheldon Brown](https://www.sheldonbrown.com/shimano-cassette-bodies.html)
- [Freehub & Cassette Compatibility — Shimano](https://productinfo.shimano.com/en/compatibility/C-731)
- [Freehub Compatibility Guide — Outside](https://velo.outsideonline.com/road/road-racing/a-guide-to-freehub-body-and-cassette-compatibility/)

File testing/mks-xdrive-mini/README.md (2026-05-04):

# MKS XDrive Mini Sprint Folder

This folder is the **single place to use during the test sprint** for the replacement motor controller.

It assumes the new board is an **MKS XDrive / MKS ODrive Mini** class controller that is broadly compatible with the legacy ODrive Python/native-protocol stack.

## Use Order

1. `00-verify-stack.ps1`
2. `01-probe-board.ps1`
3. `10-agent-control.ps1` for agent-driven commands
4. `02-open-session-panel.ps1` only if a human wants a GUI

Only use the old large GUI if you explicitly need something from it.

## Files

- `README.md`
  - quick sprint workflow
- `STACK.md`
  - detailed control-stack notes, electronics defaults, and architecture decisions
- `BARE-MOTOR-SETUP.md`
  - bare-motor bring-up workflow and first-spin helper notes
- `requirements.txt`
  - pinned local Python requirements for this sprint
- `odrive_probe.py`
  - CLI probe for USB/native-protocol bring-up
- `odrive-session-panel.py`
  - compact GUI for connect / calibrate / closed-loop / velocity / torque / position
- `mks_agent_control.py`
  - self-contained agent-safe CLI for Codex / Claude driven control
- `xdrive_first_spin.py`
  - lower-level first-spin helper retained for bare-motor bring-up
- `00-verify-stack.ps1`
  - checks Python path, imports, package versions, and key files
- `01-probe-board.ps1`
  - runs the probe with safe defaults and saves JSON output
- `02-open-session-panel.ps1`
  - launches the compact session GUI
- `03-open-zadig.ps1`
  - opens Zadig if the WinUSB/native driver still needs to be installed
- `10-agent-control.ps1`
  - passes arguments through to `mks_agent_control.py`
- `11-safe-smoke-test.ps1`
  - one-command minimal bring-up and tiny motion test
- `SESSION-CHECKLIST.md`
  - one-page session order and hard rules

## Sprint Defaults

- Python: local `.venv-odrive051\Scripts\python.exe` via `mks-python-env.ps1`
- ODrive package: `odrive==0.5.1.post0`
- USB backend: `libusb-package` DLL exposed automatically by the wrappers
- Board profile: `gearbox`
- Gear ratio: `5:1`
- Motor current limit: `10 A`
- Watchdog timeout: `0.5 s`

These are conservative defaults for bring-up. Tune later only after stable motion.

## First Session

### 1. Verify the software stack

Run:

```powershell
PowerShell -ExecutionPolicy Bypass -File .\00-verify-stack.ps1
```

Expected:

- Python found
- `odrive` import works
- `bleak` import works
- `matplotlib` import works
- required files present

### 2. If the board is not recognized by Python yet

Run:

```powershell
PowerShell -ExecutionPolicy Bypass -File .\03-open-zadig.ps1
```

Then install the WinUSB driver for the board's **native interface** if it enumerates as an ODrive-style USB device.

### 3. Probe the board first

Run:

```powershell
PowerShell -ExecutionPolicy Bypass -File .\01-probe-board.ps1
```

This:

- looks for an ODrive-compatible device
- applies the safe gearbox profile
- prints the key board/motor values
- saves a JSON summary into:
  - `qdd-gearbox/testing/data/motor-controller-probe.json`

Do **not** skip this on the first successful connection.

### 4. Preferred: let Codex / Claude drive it through the agent CLI

Run:

```powershell
PowerShell -ExecutionPolicy Bypass -File .\10-agent-control.ps1 status
```

Examples:

```powershell
PowerShell -ExecutionPolicy Bypass -File .\10-agent-control.ps1 calibrate
PowerShell -ExecutionPolicy Bypass -File .\10-agent-control.ps1 velocity --rpm 30 --seconds 2
PowerShell -ExecutionPolicy Bypass -File .\10-agent-control.ps1 torque --nm 1.0 --seconds 1
PowerShell -ExecutionPolicy Bypass -File .\10-agent-control.ps1 position --deg 90
PowerShell -ExecutionPolicy Bypass -File .\10-agent-control.ps1 idle
```

Important:

- motion commands are self-contained and auto-safe
- they connect, apply the safe profile, enter closed loop, execute, zero, and return to idle
- that is the main reason this is safer for an AI-controlled sprint workflow
- only run one USB/native-protocol client at a time
- for bare-motor bring-up, override the gearbox defaults:

```powershell
PowerShell -ExecutionPolicy Bypass -File .\10-agent-control.ps1 --profile bare --ratio 1 status
PowerShell -ExecutionPolicy Bypass -File .\10-agent-control.ps1 --profile bare --ratio 1 calibrate
PowerShell -ExecutionPolicy Bypass -File .\10-agent-control.ps1 --profile bare --ratio 1 velocity --rpm 6 --seconds 1 --calibrate
```

### 4B. One-command smoke test

Run:

```powershell
PowerShell -ExecutionPolicy Bypass -File .\11-safe-smoke-test.ps1
```

This is the fastest way to answer:

- does the board connect?
- can it calibrate?
- can it execute a tiny safe motion?
- does it return to idle?

### 5. Optional: open the session GUI

Run:

```powershell
PowerShell -ExecutionPolicy Bypass -File .\02-open-session-panel.ps1
```

Use the GUI for:

- connect
- calibrate
- enter closed loop
- idle / e-stop
- manual velocity / torque / position commands

## Fast Rules

- Probe first, GUI second
- For AI-driven control, prefer `10-agent-control.ps1`
- One USB/native-protocol client at a time
- Stay on conservative current and voltage limits during bring-up
- If anything feels wrong, go idle and cut DC power
- Real hardware evidence matters more than fancy software during this sprint

## Notes About The Package Version

The docs in the repo sometimes mention `odrive==0.5.5`, but that version is not available on PyPI.

For this sprint, the working Python stack is:

- `odrive==0.5.1.post0`
- `libusb-package`

`odrive==0.5.4` enumerated the board in Windows but did not complete a reliable native-protocol handshake on this MKS Mini.

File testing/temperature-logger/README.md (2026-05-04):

# QDD Thermistor Logger

Arduino sketch for logging gearbox or motor temperature from a thermistor voltage-divider circuit.

## Default Wiring

Default sketch constants assume:

```text
5V --- 10k fixed resistor --- A0 --- 10k NTC thermistor --- GND
```

If your circuit is reversed:

```text
5V --- 10k NTC thermistor --- A0 --- 10k fixed resistor --- GND
```

change this line in the sketch:

```cpp
const DividerMode DIVIDER_MODE = THERMISTOR_TO_GND;
```

to:

```cpp
const DividerMode DIVIDER_MODE = THERMISTOR_TO_VCC;
```

## Calibration Values

Tune these first:

```cpp
const float VREF_VOLTS = 4.35f;
const float FIXED_RESISTOR_OHMS = 10000.0f;
const float NOMINAL_RESISTANCE_OHMS = 10000.0f;
const float NOMINAL_TEMPERATURE_C = 25.0f;
const float BETA_K = 3435.0f;
```

Notes:

- `VREF_VOLTS` is set to `4.35 V`, measured on the Arduino 5V rail on 2026-05-03.
- Use the real fixed-resistor value if you can measure it.
- This setup is configured for a 10k NTC thermistor with Beta 3435.

## Upload

Open this file in Arduino IDE:

```text
testing/temperature-logger/arduino/qdd_thermistor_logger/qdd_thermistor_logger.ino
```

Use:

- Board: your Arduino model, likely Uno or Nano
- Baud: `115200`
- Serial Monitor output: CSV
- Serial Plotter: set `SERIAL_PLOTTER_MODE = true` in the sketch first

## Output Columns

```text
time_ms,adc_counts,voltage_v,resistance_ohm,temp_c,temp_f
```

## Python Logger

Install the serial dependency once:

```powershell
C:\Users\aaron\miniconda3\python.exe -m pip install -r C:\Users\aaron\Documents\c-projects\qdd-gearbox\testing\\temperature-logger\requirements.txt
```

Start a log:

```powershell
C:\Users\aaron\miniconda3\python.exe C:\Users\aaron\Documents\c-projects\qdd-gearbox\testing\\temperature-logger\log_thermistor.py --port COM6
```

Stop with `Ctrl+C`.

The logger writes timestamped CSV files to:

```text
testing/data/
```

Suggested filename:

```text
thermistor-log-YYYYMMDD-HHMMSS.csv
```

It adds a PC timestamp column ahead of the Arduino columns:

```text
pc_timestamp,time_ms,adc_counts,voltage_v,resistance_ohm,temp_c,temp_f
```

## Test-Day Workflow

1. Plug in the Arduino.
2. Confirm the port if needed:

```powershell
C:\Users\aaron\AppData\Local\Programs\Arduino IDE\resources\app\lib\backend\resources\arduino-cli.exe board list
```

3. Start the Python logger:

```powershell
C:\Users\aaron\miniconda3\python.exe C:\Users\aaron\Documents\c-projects\qdd-gearbox\testing\\temperature-logger\log_thermistor.py --port COM6
```

4. Start the gearbox/motor test.
5. Stop logging with `Ctrl+C`.
6. Add the CSV filename and test notes to `testing/validation/test-log.md`.

## Motor Test Integration

Use this wrapper when you want one motor command and a synchronized temperature CSV:

```powershell
PowerShell -ExecutionPolicy Bypass -File C:\Users\aaron\Documents\c-projects\qdd-gearbox\testing\\temperature-logger\run_motor_temp_test.ps1 -Command velocity -Profile gearbox -Ratio 5 -Rpm 10 -Seconds 5
```

What it does:

1. Starts `log_thermistor.py` on `COM6`.
2. Logs a short baseline before motion.
3. Runs the selected MKS motor command through `testing/mks-xdrive-mini/10-agent-control.ps1`.
4. Keeps logging briefly after motion.
5. Prints the temperature CSV path.

Supported commands:

```powershell
-Command velocity  -Rpm 10 -Seconds 5
-Command torque    -Nm 0.5 -Seconds 5
-Command position  -Deg 45
-Command status
-Command calibrate
-Command idle
```

For bare-motor tests:

```powershell
PowerShell -ExecutionPolicy Bypass -File C:\Users\aaron\Documents\c-projects\qdd-gearbox\testing\\temperature-logger\run_motor_temp_test.ps1 -Command velocity -Profile bare -Ratio 1 -Rpm 5 -Seconds 3
```

Use `-Calibrate` only when you intentionally want the wrapper to calibrate before the motion command.

Current bench setup verified on 2026-05-03:

- Arduino Uno detected on `COM6`
- Baud rate `115200`
- Thermistor: `10k NTC`, `Beta 3435`
- Divider mode in sketch: `THERMISTOR_TO_GND`
- Room-temperature sanity check: about `23.8 C`

For a cleaner live graph in Arduino Serial Plotter, change:

```cpp
const bool SERIAL_PLOTTER_MODE = false;
```

to:

```cpp
const bool SERIAL_PLOTTER_MODE = true;
```

That prints only `temp_c` and `voltage_v`, without the large `time_ms` value stretching the plot scale.

## Optional LCD

The sketch has disabled support for a common I2C 16x2 LCD.

To enable it:

1. Install `LiquidCrystal_I2C` in Arduino IDE.
2. Set:

```cpp
#define USE_I2C_LCD 1
```

3. Confirm the I2C address is correct:

```cpp
LiquidCrystal_I2C lcd(0x27, 16, 2);
```

Some LCD backpacks use `0x3F` instead of `0x27`.

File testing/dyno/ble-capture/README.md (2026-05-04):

# saris-h2-dyno

BLE-based dynamometer capture tool for the **Saris Hammer H2** bike trainer. Connects via Bluetooth, logs power/torque/RPM at ~1.1 Hz, and generates dyno curves.

Built to repurpose the H2 as a motor dynamometer for small-medium electric motors (e.g., ODrive D6374).

**Folder boundary:** this folder is only the executable BLE capture/control tool. Hardware assumptions, trainer limitations, adapter design notes, and test interpretation live in `testing/dyno/README.md`.

## Features

- **BLE data capture** via Cycling Power Service (0x1818) with live terminal output
- **12 data channels**: power, torque (2 derivation methods), RPM, angular velocity, angular acceleration, wheel/crank revolutions
- **6-panel dyno plots**: power, RPM, torque time history, classic dyno curve (T & P vs RPM), angular acceleration, accumulated torque
- **CSV output** for post-processing
- **Resistance control** (experimental, untested): ERG mode (constant watts) and SIM mode (simulated grade)

## Quick Start

```bash
pip install bleak matplotlib

# Capture 60 seconds of data
python dyno.py capture --duration 60 --output runs/my_run.csv

# Plot an existing capture
python dyno.py plot runs/run_001.csv --save

# Scan for the trainer
python dyno.py scan
```

## CLI Reference

```
python dyno.py capture [-d DURATION] [-o OUTPUT] [--addr ADDR] [--no-plot] [-q]
python dyno.py plot <csv_path> [--save]
python dyno.py scan [-t TIMEOUT]
```

| Flag | Description |
|---|---|
| `-d`, `--duration` | Capture time in seconds (default: 60) |
| `-o`, `--output` | Output CSV path (default: `runs/run_001.csv`) |
| `--addr` | BLE address override (default: auto-detect known H2) |
| `--no-plot` | Skip plot generation after capture |
| `-q`, `--quiet` | Suppress live sample output |
| `-s`, `--save` | Save plot as PNG alongside CSV |
| `-t`, `--timeout` | BLE scan timeout in seconds (default: 5) |

## Data Channels

| Channel | Source | Notes |
|---|---|---|
| `power_w` | CPS direct | Instantaneous power (W) |
| `acc_torque_nm` | CPS direct | Cumulative torque at 1/32 Nm resolution |
| `wheel_revs` | CPS direct | Cumulative flywheel revolution count |
| `wheel_event_time` | CPS direct | High-res timing at 1/2048 s |
| `crank_revs` | CPS direct | Cumulative crank count (0 when not pedaling) |
| `crank_event_time` | CPS direct | Crank timing at 1/1024 s |
| `rpm` | Derived | delta(revs) / delta(time) * 60 |
| `omega_rad_s` | Derived | RPM * 2pi/60 |
| `inst_torque_nm` | Derived | delta(acc_torque) / delta(revs) * 2pi |
| `torque_from_power_nm` | Derived | P / omega (cross-check) |
| `alpha_rad_s2` | Derived | delta(omega) / delta(t) |

## Device Info

| Field | Value |
|---|---|
| Model | Saris Hammer H2 (Model 320) |
| MAC | `EE:51:A8:51:70:1A` |
| Protocol | Cycling Power Service (0x1818), **not** FTMS |
| Notification rate | ~1.1 Hz (firmware-locked) |
| Max power | 2000W @ 40 km/h |
| Accuracy | +/- 2% |
| Brake type | Electromagnetic eddy current |
| Flywheel | 20 lbs (9 kg) |

## BLE Protocol Notes

The H2 does **not** use the standard FTMS (0x1826) profile. It exposes:

| Service | UUID | Purpose |
|---|---|---|
| Cycling Power | `0x1818` | Power, torque, revs (read) |
| Saris Proprietary | `c0f4013a-...` | Resistance control (write) |
| Device Information | `0x180A` | Model, firmware, serial |

### Resistance Control (Untested)

Write 10-byte commands to characteristic `ca31a533-a858-4dc7-a650-fdeb6dad4c14`:

```
[0x00] [0x10] [mode] [param_lo] [param_hi] [0x00] [0x00] [0x00] [0x00] [0x00]

Modes:
  0x01 = ManualPower (ERG) -- target watts
  0x02 = ManualSlope (SIM) -- grade * 100 (500 = 5.0%)

Timing: 3s between commands, 4-5s for brake engagement
```

Protocol source: [qdomyos-zwift](https://github.com/cagnulein/qdomyos-zwift/blob/master/src/devices/cycleopsphantombike/cycleopsphantombike.cpp)

## Project Structure

```
saris-h2-dyno/
├── dyno.py              # CLI entry point
├── saris_h2/
│   ├── __init__.py
│   ├── protocol.py      # BLE constants, CPS parser, resistance commands
│   ├── capture.py       # Async BLE session + CSV output
│   ├── control.py       # Resistance control (untested)
│   └── plot.py          # 6-panel matplotlib visualization
├── runs/                # Captured data
│   └── run_001.csv      # First test (hand spin, 2026-03-16)
└── docs/
    └── ble-protocol.md  # Detailed protocol reference
```

## Requirements

- Python 3.11+
- Windows 10+ with Bluetooth (tested on Windows 11)
- `bleak` for BLE
- `matplotlib` for plotting

## Motor Dyno Integration

The original goal is to drive the trainer flywheel with an ODrive D6374 motor:

- **Direct drive preferred**: The eddy current brake needs speed to produce torque. A 5:1 gearbox is counterproductive (gives torque the trainer doesn't need, removes speed it does).
- **ODrive USB gives 20+ Hz motor telemetry**, BLE gives ~1 Hz trainer telemetry
- **Gearbox efficiency test**: Run motor through gearbox into free-spinning trainer. Compare ODrive-side power to trainer-side power = gearbox efficiency map.

## References

- [Bluetooth CPS Spec](https://www.bluetooth.com/specifications/specs/cycling-power-service-1-1/)
- [qdomyos-zwift](https://github.com/cagnulein/qdomyos-zwift) -- Saris resistance protocol
- [pycycling](https://github.com/zacharyedwardbull/pycycling) -- Python BLE trainer library
- [DC Rainmaker H2 Review](https://www.dcrainmaker.com/2019/01/cycleops-h2-hammer-2-trainer-in-depth-review.html)

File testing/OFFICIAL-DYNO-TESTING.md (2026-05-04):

# Official Dyno Requirement Testing

This is the operator guide for the QDD dyno bench:

- MKS XDrive Mini / ODrive-compatible motor controller
- Saris Hammer H2 trainer BLE dyno
- Arduino thermistor logger
- synchronized run folders and manifests

Use these wrappers for requirement runs. They create synced run folders under `testing/data/` with:

- `manifest.json`
- `motor.log`
- `temperature.csv`
- `dyno.csv`
- `emergency-idle.log`

Raw synced run folders are local bench artifacts and are ignored by git. Commit handoff summaries under `testing/data/session-*.md` when a test session needs to be preserved.

## Safety Defaults

- `Kt = 0.04 Nm/A`
- `gear_ratio = 5`
- `target_efficiency = 0.90`
- controller current envelope: `60 A continuous`, `90 A peak`
- abort at `50 C` Arduino motor/gearbox temp
- abort at `70 C` controller FET temp
- fan installed on controller by default

The wrapper emergency-idles the controller if the Arduino temperature log or FET telemetry crosses the configured limits.

## Bench Setup

Power:

```text
PSU voltage: 24 V
PSU current limit: 10 A
OVP: 30 V
OCP: 10 A
```

Connections:

- MKS controller powered and connected over USB.
- Arduino thermistor logger on `COM6` at `115200`.
- Hammer H2 awake and discoverable over BLE.
- Controller and motor fan cooling installed.

Controller current range:

```text
requested_current_range = 70 A
verified effective_current_lim = 40 A after reboot
```

Check this before any high-current run. If `effective_current_lim` is lower than the requested test current, reboot the controller after saving the new range.

## Official Sequence

Run from `C:\Users\aaron\Documents\c-projects\qdd-gearbox\testing`.

First verify that the trainer is awake:

```powershell
& C:\Users\aaron\miniconda3\python.exe .\dyno\ble-capture\dyno.py scan --timeout 10
```

Then run preflight:

```powershell
.\run_official_requirement_test.ps1 -TestStage PreflightDirection
```

Use this first after any wiring/controller reboot. It uses a tiny positive torque bump and a low velocity trip.

## Direction Notes From 2026-05-03

Two hard constraints established this date:

1. **Negative-velocity at high targets oversped to ~+27 t/s** in the freewheel direction and tripped current limit (session 007, target -1.67 t/s @ 20 A). Do not use targets ≤ -1 t/s for official runs.
2. **Positive (loaded) direction cannot be driven bare-motor at this controller's ~70 A Iq cap** (≈ 2.8 Nm motor torque, session 008). Multiple runs at 20 A, 40 A, 60 A, 70 A torque mode and 20 A, 60 A, 90 A velocity mode → motor stalled in the loaded direction. After 150 s pinned at 70 A Iq, motor heated +9 °C, all 232 W dissipated as heat, no rotation. **The 5:1 gearbox exists because the bare motor cannot drive these loads directly — this is consistent with the design rationale.**

For a matched-load (Hammer-recording) bare-motor baseline, three options remain:

- **Hand-spin start.** Apply ~2.8 Nm at 70 A, hand-spin the wheel during the hold to break stiction, motor maintains at lower steady-state torque. Hacky but produces matched-load data.
- **Higher current burst.** Try 100–120 A peak for ≤ 10 s with strict thermal abort. Risk: FET thermal trip, motor windings stress.
- **Change methodology for R-09.** Characterize bare motor in freewheel direction at low load (motor input W vs estimated motor mech W). Characterize gearbox-installed in loaded direction at trainer (full-system input W vs Hammer output W). Compute gearbox-only efficiency by inferring motor losses from the bare curve at matched motor torque/speed. Most methodologically rigorous; avoids the bare-motor torque wall entirely.

Target speed guidance (if a valid bare-motor matched-load run is achieved):

```text
Minimum useful trainer speed target: about 100 rpm
Bare direct-drive motor target: 100 rpm / 60 = 1.67 turns/s
Gearbox-installed motor target for same trainer speed: 1.67 * 5 = 8.33 turns/s
```

For the gearbox-installed runs (where bare-motor torque is not the limit), use a gradual positive-direction ramp and strict velocity/temp aborts.

## Recovery After a Failed Run

The 2026-05-03 evening session uncovered a chain of silent-failure modes in the harness; all are now fixed in code (`safe_ramp_test.py`, `safe_torque_ramp_test.py`, `run_synced_motor_dyno_temp.ps1`). When a run still fails:

1. **Read the new state-watch printout in `motor.log`** — on a silent disarm during a run, the script now prints `disarm_reason`, `active_errors`, and per-subobject error codes at the moment of disarm.
2. **Read the post-clear printout at the start of every run.** The script prints axis/motor/encoder/controller errors after attempting to clear them. If anything is nonzero after the clear, the run will likely fail to enter CLOSED_LOOP.
3. **If sticky errors remain after a software clear: power-cycle PSU.** Off, count to 5, on. This is the only reliable reset for some sticky bits. Sticky values seen: axis `48`, `16`, `2048`; motor `32768`.
4. **Manifest summary `motor_exit_code` and `dyno_exit_code` are authoritative.** Nonzero = real failure even if the parent script reported "completed" status.

## Bare Motor Baseline

The baseline is not a torque requirement proof. It is a repeatable motor/controller/trainer operating point used later for gearbox efficiency comparison.

Required for a valid baseline:

- nonzero Hammer `rpm`
- nonzero Hammer `wheel_revs`
- nonzero Hammer `power_w`, or a clearly stable nonzero torque channel
- controller logs with `vbus`, `ibus`, `dc_W`, `Iq`, encoder velocity, FET temp
- Arduino temperature log
- manifest status `completed` and all process exit codes `0`

The 2026-05-03 attempts with zero Hammer rpm/power are diagnostics only, not efficiency data.

```powershell
.\run_official_requirement_test.ps1 -TestStage BareBaseline -Series
```

Bare motor baseline at `20 A`, `40 A`, and `60 A`.

```powershell
.\run_official_requirement_test.ps1 -TestStage GearboxEfficiency -Series
```

Gearbox-installed efficiency runs at the same current points.

```powershell
.\run_official_requirement_test.ps1 -TestStage ContinuousTorque
```

Gearbox-installed continuous torque run capped at `60 A`.

```powershell
.\run_official_requirement_test.ps1 -TestStage PeakTorque
```

Gearbox-installed peak torque ramp capped at `90 A`.

```powershell
.\run_official_requirement_test.ps1 -TestStage Speed
```

Gearbox-installed `600 RPM` output speed run.

## Efficiency Analysis

Compare one bare run folder against the matching gearbox run folder:

```powershell
& C:\Users\aaron\miniconda3\python.exe .\analyze_synced_efficiency.py `
  --bare-run .\data\synced-official-bare-baseline-40a-YYYYMMDD-HHMMSS `
  --gearbox-run .\data\synced-official-gearbox-efficiency-40a-YYYYMMDD-HHMMSS `
  --rpm-tolerance 3 `
  --output .\data\efficiency-40a.json
```

Only claim `R-09` from matched-speed pairs with enough samples. Do not use startup spikes or zero-rpm power artifacts.

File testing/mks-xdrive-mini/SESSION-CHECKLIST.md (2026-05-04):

# MKS Session Checklist

Use this in order during the sprint.

## Before Power

- DC polarity confirmed
- brake resistor connected
- motor phases tight
- motor physically secured
- encoder coupling tight
- USB data cable connected
- nothing can catch the rotor
- supply current limit set conservative

## Software Bring-Up

1. Run `00-verify-stack.ps1`
2. If driver issue: run `03-open-zadig.ps1`
3. Run `01-probe-board.ps1`
4. Check:
   - bus voltage is sane
   - no errors
   - phase resistance / inductance look sane
   - watchdog did not throw errors

## First Motion

1. Run `11-safe-smoke-test.ps1`
2. Confirm:
   - calibration completes
   - small motion is clean
   - command returns to idle

If anything is odd:

- stop using motion commands
- rerun probe
- inspect wiring / encoder / board USB path

## During Testing

- prefer `10-agent-control.ps1` for shell-driven commands
- use the GUI only if a human wants manual operation
- keep only one ODrive-compatible USB client open at a time
- after each risky step, return to `idle`

## Suggested Safe Command Set

```powershell
PowerShell -ExecutionPolicy Bypass -File .\10-agent-control.ps1 status
PowerShell -ExecutionPolicy Bypass -File .\10-agent-control.ps1 calibrate
PowerShell -ExecutionPolicy Bypass -File .\10-agent-control.ps1 velocity --rpm 10 --seconds 1
PowerShell -ExecutionPolicy Bypass -File .\10-agent-control.ps1 position --deg 45
PowerShell -ExecutionPolicy Bypass -File .\10-agent-control.ps1 torque --nm 0.5 --seconds 1
PowerShell -ExecutionPolicy Bypass -File .\10-agent-control.ps1 idle
```
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

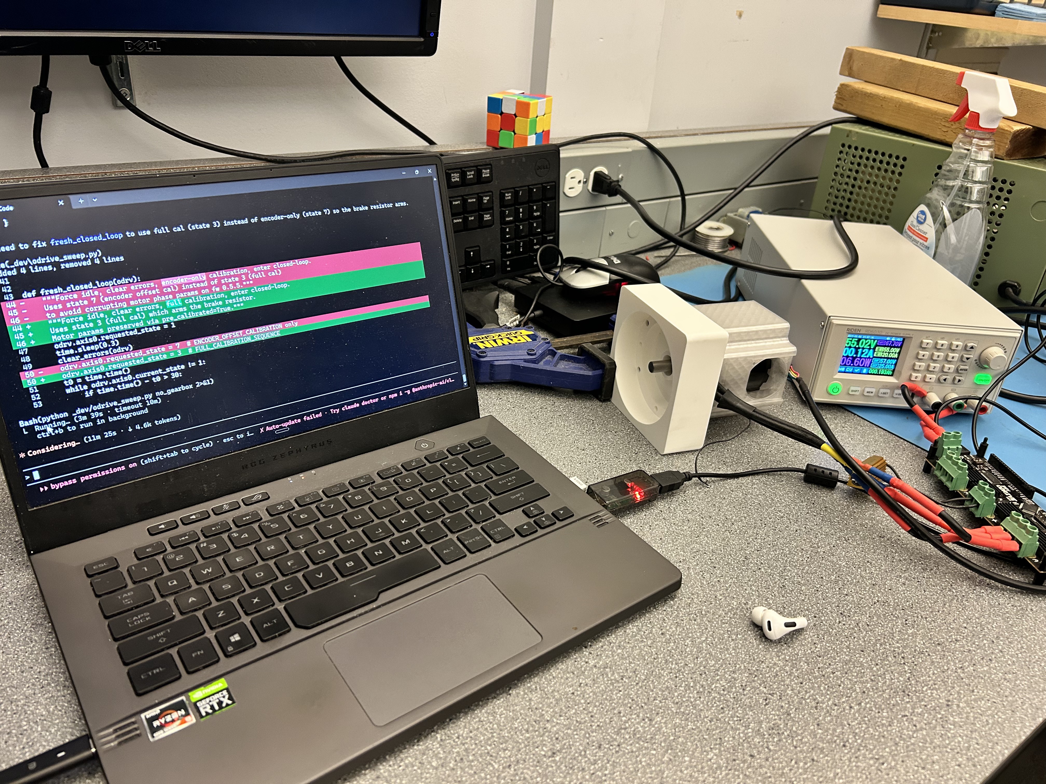
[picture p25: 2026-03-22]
prototypes/rev00b/photos/rev00b-testing-with-claude-code.jpg

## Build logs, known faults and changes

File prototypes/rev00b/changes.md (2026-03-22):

# Rev 00B — Design Changes

Consolidation of all known issues from Rev 00A. Organized by part so changes can be worked through in CATIA one part at a time.

---

## Carrier — Top

### Enlarge output shaft + larger top bearing ✅
**Source:** T-001, U-07 | **Priority:** Must-have
**Problem:** Current shaft clearly undersized.
**Solution:** Enlarged output shaft and larger top bearing — both changed parametrically in CATIA.
**Notes:**

### Fix planet bearing shoulder print quality ✅
**Source:** T-003, T-005, U-04 | **Priority:** Must-have
**Problem:** Print orientation trade-off — output shaft up gives good top bearing surface but bad planet shoulders. T-005 confirmed shoulders are sensitive to bolt torque (narrow window between carrier play and planet binding).
**Chosen approach:** Changed print strategy — top carrier no longer has walls, only bottom carrier has walls. Improves print viability for top carrier (no overhangs on shoulder surfaces).
**Notes:** No parametric/geometry change to the shoulder dimensions themselves — this is a print orientation fix.

### ~~Carrier halves indexing feature~~ — DEPRIORITIZED
**Source:** U-05, T-004 | **Priority:** Optional
**Reason:** Load path analysis shows no operational force drives clocking. ~0.5 mm play exists but is not loaded. Indexing only useful for assembly repeatability, not structural.
**Notes:**

---

## Carrier — Bottom

### Planet bearing shoulders ✅
**Source:** T-003, T-005, U-04 | **Priority:** Must-have
**Solution:** Bottom carrier now has all the walls (top carrier walls removed). No geometry change needed — bottom shoulders looked OK in visual inspection.
**Notes:**

### Adjust planet bearing clearances — NO CHANGE
**Source:** Assembly observation | **Priority:** Should-have
**Notes:** Not changing for Rev 00B.

### ~~Carrier halves indexing feature~~ — DEPRIORITIZED
(See Carrier — Top)

---

## Carrier — General (both halves)

### Thread into plastic (no heat inserts) ✅
**Source:** T-001 | **Priority:** Must-have
**Problem:** Heat inserts not worth it for prototype iteration. Self-tap holes already validated with coupon (M3: 2.6mm, M4: 3.6mm, M5: 4.6mm).
**Solution:** Top carrier M5 output shaft holes changed to 4.2mm. Bottom carrier M3 thread holes changed from 2.6mm to 2.4mm.
**Notes:**

---

## Lid

### Redesign lid constraint — decouple ring gear clamping from carrier constraint
**Source:** T-002, U-03 | **Priority:** Must-have
**Problem:** Lid double-constrains ring gear + carrier top. Tolerance stackup through carrier assembly causes drag.
**Options:**
- (a) Add axial clearance between lid bearing and carrier top shaft
	- added extra axial clearance on carrier top shaft
- (b) Deepen lid bearing recess
- (c) Space lid out further from ring gear
**Chosen approach:** (a) Added extra axial clearance on carrier top shaft.
**Notes:**

### Lid-to-body indexing
**Source:** Prototype notes | **Priority:** Should-have
**Problem:** Lid currently only constrained against twist by clamping friction — needs positive indexing feature.
**Solution:**
**CATIA params changed:**
**Notes:** Ignoring for now. not a concern

---

## Housing Body

### Main bearing shaft fit slightly tighter
**Source:** Post-REV00A notes | **Priority:** Should-have
**Problem:** Currently loose transition fit, should be slightly tighter.
**Solution:**
**CATIA params changed:**
**Notes:** ignoring for now

---

## Motor Housing

### Bottom shaft cutout — investigate misalignment or enlarge
**Source:** Prototype notes | **Priority:** Should-have
**Problem:** Shaft rubs opposite end when mounted. Root cause unclear — could be misalignment or just undersized cutout.
**Solution:**
**Notes:** Ignoring for now

---

## Gears (Sun, Planets, Ring)

### Switch from herringbone to spur gears (0° helix)
**Source:** T-001 observation | **Priority:** Must-have
**Problem:** Herringbone helix is very slight, not providing meaningful benefit at this scale. Over-constrains the mesh and creates an assembly error mode (wrong alignment) that's hard to detect. At least one planet was misaligned in Rev 00A.
**Solution:** Reprint all gears with 0° helix angle.
**pygeartrain params changed:**
**Notes:**

### Add text features for gear top/bottom identification
**Source:** Prototype notes | **Priority:** Nice-to-have
**Problem:** Currently unclear which way gears install. Less critical with spur gears (no helix alignment), but still useful for assembly.
**Solution:**
**Notes:**

### Sun gear fit — possibly slightly looser
**Source:** Post-REV00A notes | **Priority:** Should-have
**Problem:** Currently tight enough to need pressing on table (10.075mm was tried for Rev 00A-B).
**Solution:**
**CATIA params changed:**
**Notes:**

---

## Encoder Housing

### Wire cutout + base 0.5mm thinner
**Source:** Prototype notes | **Priority:** Should-have
**Problem:** No wire routing, base too thick.
**Solution:**
**CATIA params changed:**
**Notes:**

---

## Skeleton (global)

### Clearance parameter naming — clarify higher = tighter or looser
**Source:** Prototype notes | **Priority:** Nice-to-have
**Problem:** Currently confusing which direction offset values go.
**Solution:**
**Notes:**

---

## Pending Investigation

- **Carrier shoulder deformation** — need quantitative measurement (T-003), not just visual. Current visual says bottom OK, top has print quality issues.
- **3D printer dimensional bias on sun-planet clearance** — hypothesis that printer growing ODs squeezes sun-planet gap (both grow into same space) while ring-planet self-compensates. Backlash observed with sun installed suggests tolerances may be OK, but worth measuring to confirm.

## Design Decisions Still Needed

- Which approach for lid constraint fix?
- Which approach for top carrier shoulders?
- Metal spacers vs redesigned geometry — trade-off between part count and print quality

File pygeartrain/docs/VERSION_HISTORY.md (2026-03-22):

# HackathonActuator Version History

Complete history of all gear generation versions, variations, and lessons learned.

---

## Quick Reference

| Version | Script | Output | Planets | Clearance | Key Feature |
|---|---|---|---|---|---|
| v1-v14 | `generate_planetary_cad_v*.py` | XYZ curves | 3 | N/A | Iterating on herringbone compensation |
| v15 | `generate_planetary_cad_v15.py` | XYZ curves | 3 | N/A | Return to ring-only compensation |
| v16 | `generate_planetary_cad_v16.py` | XYZ curves | 3 | -0.05mm | **Working** - CATIA macro workflow |
| v17 (STEP) | `generate_step_v17.py` | STEP/STL | 3 | -0.05mm | First CadQuery direct export (48/18/12) |
| v18 | `generate_step_v18.py` | STEP/STL | 3 | -0.20mm | Print-in-place (too loose) |
| v19 | `generate_step_v19.py` | STEP/STL | 3 | -0.10mm | Optimized clearance |
| v20 | `generate_step_v20.py` | STEP/STL | **4** | -0.10mm | Added 4th planet for torque |
| v20B | `generate_step_v20B.py` | STEP/STL | 4 | -0.10mm | **Split ring** with M3 bolts |
| v20c | `create_v20c_clearance.py` | STL only | 4 | Variable | Post-process gap creation |
| v21 | `generate_step_v21.py` | STEP/STL | 4 | **+0.05mm** | **30° helix**, interference fit |

---

## Two Parallel Pipelines

### 1. XYZ Curve Pipeline (v1-v16)
**For: 3DExperience CATIA import**

Generates XYZ text files with gear profiles at three Z-levels (z_neg, z0, z_pos) for lofting in CAD.

- **Scripts:** `generate_planetary_cad_v*.py`
- **Output:** `output_herringbone_v*/` - XYZ text files
- **Macro:** `ImportGearbox_v16.vbs` - Creates profiles and lofts in CATIA
- **Gear params:** R30/P12/S6, 3 planets, 70mm ring OD, 10mm thick

### 2. CadQuery STEP Pipeline (v17-v20B)
**For: Direct STEP/STL export**

Uses CadQuery to generate solid geometry directly - no CAD import needed.

- **Scripts:** `generate_step_v*.py`
- **Output:** `step_output_v*/` - STEP and STL files
- **Gear params:** R48/P18/S12, 3-4 planets, 80mm ring OD, 22mm thick

---

## Version Details

### XYZ Curve Versions (for CATIA)

#### v1-v2: Wrong rotation center
**Problem:** Applied herringbone twist around global origin for all gears.
**Lesson:** Planets must twist around their own centers, not the global origin.

#### v3: Basic herringbone with mesh rotation
**Problem:** Sun-planet mesh worked, but planet-ring mesh misaligned at z≠0.
**Lesson:** Different rotation centers (planet vs global) cause angular drift that must be compensated.

#### v4-v6: Wrong compensation formulas
**Problem:** Tried various theoretical formulas that didn't match reality.
**Lesson:** Don't trust derived formulas blindly - validate empirically.

#### v7-v8: Multi-gear compensation (FAILED)
**Problem:** Changed sun/planet instead of just ring - broke working sun-planet mesh.
**Lesson:** When something works, DON'T TOUCH IT. Isolate changes to what's broken.

#### v9: Empirical sweep approach
**Solution:** Created tile visualization sweeping ring rotation values.
**Finding:** Found correct neighborhood (~0.34°).
**Lesson:** When theory fails, use systematic empirical search.

#### v10-v12: Iterative refinement
- v10: Formula gave 0.341°, but overshot (0.131° remaining error)
- v11: Measured 0.21°, very close (0.0007° remaining)
- v12: Iterated to 0.21068° - **perfect** 0° offset

#### v13-v14: Multi-compensation attempt (FAILED)
**Problem:** Tried adding sun compensation (+3.44°) and carrier compensation.
**Result:** Broke planet-ring alignment. Compensations are coupled.
**Lesson:** Simple is better. Don't add complexity if simpler solution works.

#### v15: Return to simplicity
**Solution:** Copied v9 approach (ring-only compensation). Ran sweep comparison.
**Finding:** 0.2° ring offset is optimal (0.011° error).

#### v16: Manufacturing tolerance (WORKING)
**Solution:** Added -0.05mm profile offset to thin teeth for clearance.
**Result:** ~0.10mm clearance at mesh interfaces.
**Status:** Successfully imported into 3DExperience CATIA.

**Files:**
- `generate_planetary_cad_v16.py` - Generates XYZ curves
- `ImportGearbox_v16.vbs` - CATIA macro
- `output_herringbone_v16/` - Output files

---

### CadQuery STEP Versions

#### v17: First CadQuery port
**Purpose:** Generate STEP/STL directly without CAD software.
**New gear params:** R48/P18/S12 (larger teeth), 80mm ring OD, 22mm thick
**Clearance:** -0.05mm per gear (0.10mm total)
**Planets:** 3

**Files:**
- `generate_step_v17.py`
- `step_output_v17/` - sun.step/stl, planet_0-2.step/stl, ring.step/stl, assembly

#### v18: Print-in-place (loose)
**Purpose:** Increase clearance for FDM print-in-place.
**Clearance:** -0.20mm per gear (0.40mm total)
**Result:** Too loose - gears have excessive backlash.

#### v19: Optimized clearance
**Purpose:** Balance between printability and backlash.
**Clearance:** -0.10mm per gear (0.20mm total)
**Result:** Good balance - tight but printable on tuned printers.

#### v20: Four planets
**Purpose:** Increase torque capacity by adding 4th planet.
**Planets:** 4 (at 0°, 90°, 180°, 270°)
**Clearance:** -0.10mm per gear

**Files:**
- `generate_step_v20.py`
- `step_output_v20/` - sun, planet_0-3, ring, assembly

#### v20B: Split ring with M3 bolts (CURRENT)
**Purpose:** Assemble-able version (not print-in-place).
**Key changes:**
- Ring split at z=0 into top and bottom halves
- 6x M3 screw holes for bolting halves together
- Counterbored clearance holes in one half, tap holes in other
- 5mm ring wall thickness

**Files:**
- `generate_step_v20B.py`
- `step_output_v20B/`:
  - `sun.step/stl`
  - `planet_0.step/stl` through `planet_3.step/stl`
  - `ring_top.step/stl`
  - `ring_bottom.step/stl`
  - `gearbox_assembly.step/stl`

**Print Test Results (2026-01-31):**

✅ **What worked:**
- Two-part ring assembly works well for assembly
- Everything printed decently
- Low friction

❌ **Issues:**
- Clearances too generous - gears shift/sink noticeably when picked up
- Some gears have slop

💡 **Ideas for v21:**
- Fewer teeth to take advantage of the tooth profile style
- Reduce tolerance to 0mm or introduce interference fit
- Rely on plastic squish during assembly to compensate for interference

#### v21: Tight Fit + Steeper Helix (2026-01-31)
**Purpose:** Zero backlash gearbox with better axial resistance.
**Key changes from v20B:**
- Helix angle: 30° (was 20°) - more axial resistance to prevent sinking
- Interference fit: +0.05mm (was -0.10mm clearance) - relies on plastic squish
- Same teeth: R48/P18/S12, 4 planets, 5:1 ratio

**Files:**
- `generate_step_v21.py`
- `step_output_v21/`:
  - `sun.step/stl`
  - `planet_0.step/stl` through `planet_3.step/stl`
  - `ring_top.step/stl`
  - `ring_bottom.step/stl`
  - `gearbox_assembly.step/stl`

**Validation added:** Script now checks all planetary gear rules before generating:
1. Mesh constraint: R = S + 2P
2. Assembly constraint: (R + S) % N == 0
3. Planet non-interference: (S + P) × sin(π/N) > P + 2
4. Minimum teeth: S ≥ 6, P ≥ 6
5. Planet count: 2 ≤ N ≤ 8

---

#### v20c: Post-process gap creation
**Purpose:** Add gaps at contact points without changing overall profiles.
**Method:** Finds vertices too close to neighbors, pushes them apart.
**Params:** MIN_GAP=0.08mm, THRESHOLD=0.15mm
**Output:** STL only (mesh-based operation)

---

## Key Parameters

### Original CATIA workflow (v16)
```
Ring teeth:     30
Planet teeth:   12
Sun teeth:      6
N planets:      3
Helix angle:    20°
Ring OD:        70mm
Thickness:      10mm
b-profile:      0.2
Ring offset:    0.2° (compensation)
Profile offset: -0.05mm
```

### CadQuery workflow (v17-v20B)
```
Ring teeth:     48
Planet teeth:   18
Sun teeth:      12
N planets:      3 (v17-v19) or 4 (v20+)
Helix angle:    20°
Ring OD:        80mm
Thickness:      22mm
b-profile:      0.5
Ring offset:    0.2° (compensation)
Profile offset: -0.10mm (v19+)
Ring wall:      5mm (v20B)
```

### v21 Parameters
```
Ring teeth:     48
Planet teeth:   18
Sun teeth:      12
N planets:      4
Helix angle:    30° (was 20°)
Ring OD:        80mm
Thickness:      22mm
b-profile:      0.5
Ring offset:    0.2° (compensation)
Profile offset: +0.05mm (INTERFERENCE - was -0.10mm)
Ring wall:      8mm
```

### Geometry constraint
```
R = S + 2P
```
Ring teeth = Sun teeth + 2 × Planet teeth

### Gear ratio
```
Ratio = (R + S) / S
```
- v16: (30 + 6) / 6 = 6:1
- v17+: (48 + 12) / 12 = 5:1

---

## The Ring Compensation Formula

The key insight for herringbone planetary gears:

```python
# Planets rotate around their own centers
# Ring rotates around global origin
# This causes mesh drift at z ≠ 0

ring_compensation = z × tan(helix_angle) × (1/ring_inner_r - 1/mesh_radius)

where:
  mesh_radius = carrier_radius + planet_outer_radius
```

This formula gets within ~0.2° of perfect. One iteration of empirical measurement achieves 0°.

---

## Lessons Learned Summary

1. **Isolate changes** - Only modify what's broken, preserve what works
2. **Validate empirically** - Theory gives estimates, measurement gives truth
3. **Use visual sweeps** - When stuck, create parameter sweeps
4. **Understand geometry** - Ring compensation exists because planets orbit at offset
5. **Iterate to precision** - Formula → Measure → Adjust → Repeat
6. **Simple > complex** - Ring-only compensation beats multi-compensation
7. **Two-phase macros** - Create all profiles before lofts to prevent cascade failures

---

## Output File Locations

### XYZ Curves (for CATIA import)
```
output_herringbone/           # Initial test
output_herringbone_v12-v17/   # Various iterations
output_herringbone_final/     # Clean working set
```

### STEP/STL (ready to print/import)
```
step_output_v17/              # 3 planets, 0.10mm clearance
step_output_v18/              # 3 planets, 0.40mm clearance (too loose)
step_output_v19/              # 3 planets, 0.20mm clearance (optimized)
step_output_v20/              # 4 planets, 0.20mm clearance
step_output_v20B/             # 4 planets, split ring with M3 bolts
step_output_v20c/             # 4 planets, post-processed gaps (STL only)
step_output_v21/              # 4 planets, 30° helix, +0.05mm interference ← CURRENT
```

---

## Next Steps / Ideas

### v21 Implemented
- [x] **Tighter tolerances** - +0.05mm interference fit (v21)
- [x] **Steeper helix** - 30° for better axial resistance (v21)
- [x] **Gear validation** - Script checks all rules before generating

### v22+ Ideas (pending v21 print test)
- [ ] Add carrier geometry to STEP output
- [ ] Parametric script for different gear ratios
- [ ] Blender render workflow for portfolio images
- [ ] Motor mount integration
- [ ] Bearing seats for planets

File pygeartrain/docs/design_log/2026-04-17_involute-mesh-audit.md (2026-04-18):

# 2026-04-17 Involute Mesh Audit

## Current Generator State

- Family: `R72 / P27 / S18`
- Pressure angle: `20.0 deg`
- Module: `1.0204 mm`
- Current static phases (deg): sun `8.3333`, planet `11.1111`, ring `0.4167`

## Current Static Pair Metrics

- Sun-planet sampled overlap count: `0`
- Sun-planet min sampled boundary gap: `0.0123 mm`
- Planet-ring sampled overlap count: `720` (not reliable for internal-ring inside/outside classification)
- Planet-ring min sampled boundary gap: `0.0105 mm`

## Notes

- This audit follows the same static body placement as the STEP assembly export.
- It is a sampled-outline screen, not a full analytic tooth-contact solver.
- It is intended to catch obvious indexing mistakes quickly before export or print.
- The expensive phase sweep was removed because it was too slow to be useful in this workflow.
- For the internal ring pair, use the sampled minimum gap and direct solid-intersection checks, not the overlap count alone.

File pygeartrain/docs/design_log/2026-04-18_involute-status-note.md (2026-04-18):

# 2026-04-18 Involute Status Note

## Scope

- This note covers only the involute development path.
- The original cycloidal generator at `pygeartrain/generate_step_aaron.py` is intentionally unchanged and remains the reference path.

## Current Involute Files

- `pygeartrain/generate_step_aaron_involute.py`
- `pygeartrain/generate_step_aaron_cq_gears.py`
- `calc/involute_print_verification.py`
- `calc/involute_mesh_audit.py`

## Current State

- The current packaging-matched involute baseline is `R72 / P27 / S18` at `20 deg`.
- The assembly export path is `pygeartrain/generate_step_aaron_cq_gears.py`.
- The current assembly STEP export is intended to come out already positioned correctly in one export step.
- Static phasing is no longer being judged by the old preview logic alone.
- Root cause of the apparent overlap: the old static preview path rotated each planet body with its orbit angle, while the solid STEP assembly path uses a constant planet tooth phase at each translated planet center.
- Direct solid checks for the current static STEP placement gave zero intersection volume for sun-vs-planet and ring-vs-planet on all three planets.
- A fast sampled-outline audit now follows the same static body placement as the STEP export path.
- Current verified static outputs:
  - `pygeartrain/step_output_aaron_cq_gears/spur/011/gearbox_CAD.step`
  - `pygeartrain/step_output_aaron_cq_gears/spur/011/mesh_preview_contact.png`
  - `pygeartrain/docs/design_log/2026-04-17_involute-mesh-audit.md`

## Important Dependency Note

- The local clone at `C:/Users/aaron/Documents/c-projects/_dump/cq_gears` was patched during this work so `PlanetaryGearset` forwards `addendum_coeff` and `dedendum_coeff` into the generated sun, planet, and ring gears.
- That dependency patch is outside the `qdd-gearbox` repo and is therefore not captured by this repo commit.
- Next revision should either vendor that change into the repo or remove the dependency on the external patched clone.

## Next Revision Focus

- Replace the slow mesh-audit approach with a fast sampled-outline audit.
- Use that audit to verify or correct the static phasing analytically instead of by preview image inspection.
- Keep the same ratio and keep the cycloidal path untouched.

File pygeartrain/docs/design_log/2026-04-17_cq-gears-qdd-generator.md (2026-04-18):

# 2026-04-17 — QDD Involute Generator Using `cq_gears`

## Decision

For a working involute planetary export path, use:

- `pygeartrain/generate_step_aaron_cq_gears.py`

This is now the recommended involute path over the custom one-off involute script.

## Why this path won

The custom involute copy was building:

- sun profile independently
- planet profile independently
- ring profile independently

That made phase/indexing fragile.

`cq_gears` already provides:

- involute spur / helical / herringbone gears
- ring gears
- planetary gearsets
- a native `PlanetaryGearset.assemble()` method with explicit initial tooth phasing

Sources:

- local cloned repo: `_dump/cq_gears`
- upstream README: [meadiode/cq_gears](https://github.com/meadiode/cq_gears)

The README explicitly says it supports:

- spur gear
- helical gear
- herringbone gear
- ring gear
- planetary gearsets

## Current QDD setup

The script currently targets the QDD envelope with:

- tooth counts: `R72 / P27 / S18`
- carrier/orbit radius target: `22.959 mm`
- cycloidal fit targets:
  - sun OD: `19.898 mm`
  - planet OD: `29.082 mm`
  - ring inner tip diameter: `71.938 mm`
  - ring root diameter: `75.000 mm`
  - ring OD: `95.000 mm`
- teeth: `R48 / P18 / S12`
- face width: `18.6 mm`
- pressure angle: `20 deg`
- backlash: `0.08 mm`
- addendum coefficient: derived from the cycloidal fit targets
- dedendum coefficient: derived from the cycloidal fit targets

The involute ratio remains the same as the cycloidal set. The current baseline uses a higher same-ratio tooth-count family than the original `12/18/48` involute attempt because the original family was too shallow and failed the simple external contact-ratio screen.

## Outputs

Each run writes to:

- `pygeartrain/step_output_aaron_cq_gears/<gear_type>/<run>/`

Current outputs include:

- `sun_PRINT.step/.stl`
- `planet_0_PRINT.step/.stl` through `planet_2_PRINT.step/.stl`
- `ring_PRINT.step/.stl`
- `gearbox_CAD.step` — assembly STEP
- `gearbox_CAD_compound.step` — compound STEP
- `mesh_preview_full.png`
- `mesh_preview_zoom.png`
- `mesh_preview_contact.png`
- `mesh_animation.gif`
- `sun_planet_contact_geometry.png`
- `sun_planet_contact_slowmo.gif`

## Contact diagnostics

The script now also writes a focused sun-planet diagnostic view:

- `sun_planet_contact_geometry.png`
- `sun_planet_contact_slowmo.gif`

These emphasize one mesh pair and overlay classic involute references:

- pitch circles — dashed
- base circles — dotted
- line of centers — grey
- line of action — purple
- pitch point — black dot
- estimated instantaneous contact point — magenta dot

The magenta contact point is an estimate based on nearest sampled points on the
two tooth outlines. It is a good visual diagnostic, but it is not yet a full
analytical contact solver.

## Verification

Verified working run:

- `pygeartrain/step_output_aaron_cq_gears/spur/000`
- `pygeartrain/step_output_aaron_cq_gears/spur/001`
- `pygeartrain/step_output_aaron_cq_gears/spur/005`
- `pygeartrain/step_output_aaron_cq_gears/spur/006`
- `pygeartrain/step_output_aaron_cq_gears/spur/008`

Observed result:

- assembly export completed in one pass
- `spur/005` is the first fit-matched involute export
- STEP measurements from `spur/005` match the cycloidal envelope:
  - sun STEP OD: `19.898 mm`
  - planet STEP OD: `29.082 mm`
  - ring STEP OD: `95.000 mm`
  - assembly STEP OD: `95.000 mm`
- gear ratio is preserved because tooth counts stayed `R48 / P18 / S12`

`spur/006` is the fast assembly-only export with the involute mesh tuned from the
cycloidal print clearance intent.

- cycloidal reference used: `0.13 mm` total mesh clearance
- mapped involute radial root clearance: `0.065 mm`
- mapped involute backlash factor at `m = 1.5306`, `25 deg`: `0.0911`
- assembly STEP bounding box: `95.0 x 95.0 x 18.6 mm`
- no individual gear STEP/STL files exported by default

`spur/008` is the current printable involute baseline:

- family: `R72 / P27 / S18`
- pressure angle: `20 deg`
- same fit envelope as the cycloidal set
- external sun-planet contact ratio estimate: `1.236`
- materially better visible tooth proportions than the old `12/18/48` involute
- exported assembly file: `step_output_aaron_cq_gears/spur/008/gearbox_CAD.step`

See [2026-04-17_involute-print-verification.md](C:/Users/aaron/Documents/c-projects/qdd-gearbox/pygeartrain/docs/design_log/2026-04-17_involute-print-verification.md) for the more explicit verification summary.

## Important fix

The local `_dump/cq_gears` clone needed a small fix before fit retuning would work:

- `SpurGear` already accepted `addendum_coeff` / `dedendum_coeff`
- `RingGear` did not
- `PlanetaryGearset` was not forwarding those coefficients into the sun / planet / ring constructors

That forwarding path is now patched locally, which is why `spur/005` finally matches the cycloidal fit envelope.

## Notes

- The script currently imports `cq_gears` from the local clone in `_dump/cq_gears`
- This is intentional for speed; it avoids spending more time reimplementing involute meshing logic manually
- If this becomes the permanent path, the next cleanup step is to vendor or install `cq_gears` in a more formal location

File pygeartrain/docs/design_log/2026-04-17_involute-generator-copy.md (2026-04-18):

# 2026-04-17 — Involute Generator Copy: Phase Fix + Print Tweaks

## Scope

Work applies only to:

- `pygeartrain/generate_step_aaron_involute.py`

The original cycloidal exporter in `pygeartrain/generate_step_aaron.py` was left intact.

## Problem

The first involute preview exported valid solids, but the teeth were visibly out of phase:

- planet teeth did not index correctly against the sun
- ring teeth did not line up with the planet gaps
- root transitions were sharp and not ideal for FDM printing

## Root cause

The original cycloidal generator *does* predefine the interfacing, but only because it generates a single internally consistent gear set through `PlanetaryGeometry.create(...)` and `planetary.generate_profiles(...)`.

That path:

- creates ring, planet, and sun from the same cycloidal construction
- uses a shared tooth-phase convention during profile generation
- applies a special even-tooth sun offset before animation/export
- then uses `arrange(...)` only to move an already meshing set through kinematic motion

The first involute copy did **not** have that property.

It built:

- sun profile independently
- planet profile independently
- ring profile independently

Each profile started from its own local tooth-center reference, then I reused only the carrier-placement term from the cycloidal arrangement logic:

- `spin = (1 - R/P) * carrier_angle`

That was not enough for involute geometry, because there was no shared initial tooth indexing between:

- sun vs planet
- planet vs ring

So the gears were not "mathematically broken" at the pitch-diameter level. They were missing the **base phase relationship** that the original cycloidal path gets implicitly from its shared generator.

## Changes made

### 1. Added involute-specific mesh phase offsets

The cycloidal arrangement logic was not enough on its own for the involute copy.

- Added a fixed planet base phase offset before applying the carrier-dependent spin term
- Added a fixed ring base phase offset so the internal teeth line up with the planet gaps

These are now reported in script output for traceability.

### 2. Kept the overall gearbox size envelope the same

Did **not** increase module, because for a fixed tooth count that would force a larger pitch diameter and drift away from the current QDD package size.

Instead, the involute copy keeps:

- `R48 / P18 / S12`
- ring pitch diameter target = `75 mm`

That preserves the general size reference from the existing cycloidal setup.

### 3. Switched to more print-friendly tooth proportions

Changed from a more standard full-depth involute toward a stubbier, stronger tooth:

- pressure angle: `20 deg -> 25 deg`
- addendum coefficient: `1.00 -> 0.85`
- dedendum coefficient: `1.25 -> 1.00`

Intent:

- thicker tooth bases
- less undercut risk pressure on the low-tooth-count sun
- less slender tooth tips for FDM

### 4. Added root blending

The earlier version effectively had a hard transition from root circle to involute flank.

Added a root blend in the involute copy:

- cubic blend segment between root circle and involute flank
- blend radius target = `0.45 mm`

Intent:

- reduce stress concentration
- reduce sharp internal corners
- produce a shape that is more printable and less notch-sensitive

This is a print-oriented blend, not a strict trochoid fillet model.

### 5. Increased backlash slightly

Changed per-gear radial profile offset from:

- `-0.025 mm -> -0.040 mm`

Intent:

- give the printed involute teeth a bit more assembly margin
- reduce the chance that printer OD growth locks the mesh

## Verification outputs

The involute copy now saves 2D top-down verification images in each run folder:

- `mesh_preview_full.png`
- `mesh_preview_zoom.png`
- `mesh_preview_contact.png`
- `mesh_animation.gif`

These are meant for quick visual checks of:

- tooth outline shape
- phasing
- sun/planet and planet/ring mesh alignment
- rolling motion across a short kinematic cycle

## Follow-up

If this involute path becomes more serious, the next improvement should be:

- true involute profile-shift support for the low-tooth-count sun

That would be a more correct way to fight undercut than continuing to push printability only through pressure angle and stub tooth proportions.

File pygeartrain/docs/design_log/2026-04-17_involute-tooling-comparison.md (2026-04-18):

# 2026-04-17 — Involute Tooling Comparison

## Context

Current workspace status:

- Original QDD path uses a forked `pygeartrain`, originally from [EelcoHoogendoorn/pygeartrain](https://github.com/EelcoHoogendoorn/pygeartrain)
- Cycloidal planetary generation still fits the original `pygeartrain` model well
- The involute work is currently in a standalone copy:
  - `pygeartrain/generate_step_aaron_involute.py`

## Original animation path

The original library still supports animation through the geometry classes:

- local code: `pygeartrain/pygeartrain/core/geometry.py`
- methods: `animate()` and `save_animation()`

That matches the upstream repo description that concrete gear profile geometries can be "plot and animate[d] ... to validate their intended functioning" ([upstream pygeartrain README](https://github.com/EelcoHoogendoorn/pygeartrain)).

## Why the involute copy drifted out of sync

The root cause was **not** that planetary equations were wrong.

The original `pygeartrain` planetary path works because:

- one coherent gear set is generated together
- the internal tooth indexing is consistent before any motion is applied
- the `arrange(...)` step then moves an already-meshing set

The first involute copy did something different:

- sun generated independently
- planets generated independently
- ring generated independently
- then only the carrier-placement logic was reused

That meant there was no shared initial tooth phase between:

- sun and planet
- planet and ring

So the 2D/GIF motion was not a true inherited `pygeartrain` meshing result. It was a custom placement/rotation approximation layered on top of independently generated involute profiles.

## Candidate alternatives

### 1. `heartworm/py_gear_gen`

Repo: [heartworm/py_gear_gen](https://github.com/heartworm/py_gear_gen)

What the README explicitly claims:

- involute spur gear generation
- adjustable accuracy
- gear root filleting
- internal ring gearing option
- adjustable module, tooth number, pressure angle, and backlash

Source: repo README on GitHub.

Limitations explicitly acknowledged by the author:

- author says it was their "first foray" and there may be math errors
- docs are minimal: "check out `example_usage.py` and comments"
- TODO includes:
  - review all mathematics and algorithms
  - get fillets working on internal gears
  - STL output for helical and other gears

Fit for QDD:

- good as a **2D involute reference**
- useful if the main need is spur/ring profile generation with backlash
- weaker fit for the current workflow because it does not present itself as a mature 3D/CadQuery planetary export tool

### 2. `meadiode/cq_gears`

Repo: [meadiode/cq_gears](https://github.com/meadiode/cq_gears)

What the README explicitly claims:

- CadQuery-based involute gear parametric modelling
- can generate:
  - spur
  - helical
  - herringbone
  - ring gear
  - planetary gearsets
  - bevel gears
  - racks

Source: repo README on GitHub.

Important caveat explicitly stated in the README:

- "Work in progress..."
- "Might be unstable, but somewhat usable."

Other practical notes from the README:

- requires CadQuery
- examples are provided
- build model is already CadQuery-native rather than 2D-first

Fit for QDD:

- strongest functional fit for the current workflow
- especially relevant because the current QDD script already uses CadQuery for STEP/STL export
- likely a better base if the goal is to move from ad-hoc involute export toward a more complete involute planetary generator

## Recommendation

If we keep involute work alive, the best next candidate is:

- `cq_gears`

Reason:

- it already targets involute geometry
- it already supports ring gears and planetary gearsets
- it is CadQuery-native, which matches the current export flow much better than a 2D SVG/DXF-first script

`py_gear_gen` is still useful as a compact math/reference implementation, but it looks more like a profile generator than a full replacement for the current QDD export path.

## Practical next step

Best next move is not to keep expanding the current standalone involute copy blindly.

Instead:

1. keep the current copy as a sandbox/reference
2. evaluate whether `cq_gears` can directly produce the QDD involute planetary set
3. if yes, pivot involute generation onto that base rather than reimplementing more meshing logic manually

## Files affected locally

- `pygeartrain/generate_step_aaron_involute.py`
- `pygeartrain/docs/design_log/2026-04-17_involute-generator-copy.md`
- this note

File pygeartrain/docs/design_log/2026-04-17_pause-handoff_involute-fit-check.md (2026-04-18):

# 2026-04-17 Pause Handoff - Involute Fit / Assembly Verification

## Current Recommended Script

- Script: [generate_step_aaron_cq_gears.py](C:/Users/aaron/Documents/c-projects/qdd-gearbox/pygeartrain/generate_step_aaron_cq_gears.py)
- Status: this is now the preferred involute path because it uses `cq_gears`' native planetary assembly logic instead of the earlier standalone involute sandbox.

## Why This Path Was Chosen

- The original cycloidal export path in `generate_step_aaron.py` is still intact.
- The earlier custom involute copy drifted out of phase because it generated sun, planet, and ring independently and only reused carrier placement math.
- `cq_gears` provides a native involute planetary assembly path, so the initial mesh phasing is much more trustworthy.

## What Is Already Working

- The `cq_gears` script successfully generates:
  - a STEP assembly
  - a compound STEP
  - individual gear STEP/STL files
  - mesh preview PNGs
  - a general mesh GIF
  - a slow contact diagnostic image/GIF path
- Previously verified complete output:
  - [spur/001](C:/Users/aaron/Documents/c-projects/qdd-gearbox/pygeartrain/step_output_aaron_cq_gears/spur/001)

## What Was Retuned Most Recently

The latest edit to `generate_step_aaron_cq_gears.py` retunes the involute geometry to match the **cycloidal fit envelope**, instead of using a generic involute module choice.

Reference targets taken from the confirmed cycloidal notes:

- carrier radius: `22.959 mm`
- sun OD: `19.898 mm`
- planet OD: `29.082 mm`
- ring inner tip diameter: `71.938 mm`
- ring root diameter: `75.000 mm`
- ring outer diameter: `95.000 mm`

These targets came from:

- [skeleton-step-current-state.md](C:/Users/aaron/Documents/c-projects/qdd-gearbox/docs/catia/skeleton-step-current-state.md)
- original cycloidal exports under [step_output_aaron/spur/000](C:/Users/aaron/Documents/c-projects/qdd-gearbox/pygeartrain/step_output_aaron/spur/000)

## Important Derived Involute Fit Values

These are now computed in the script from the cycloidal reference dimensions:

- module: `2 * carrier_radius / (sun_teeth + planet_teeth)`
- addendum coefficient: averaged from:
  - sun OD target
  - ring inner tip target
- dedendum coefficient: averaged from:
  - planet OD target
  - ring root target
- rim width: derived from ring OD minus ring root diameter

The tooth counts remain:

- ring: `48`
- planet: `18`
- sun: `12`
- planets: `3`

That means the involute copy is still preserving the same tooth-count-based reduction structure as the cycloidal set.

## Measurements Already Collected

### Original cycloidal export dimensions

Measured / confirmed from notes and STEP checks:

- sun OD: about `19.898 mm`
- planet OD: about `29.082 mm`
- ring OD: `95.000 mm`
- ring root diameter: `75.000 mm`
- ring inner tip diameter: about `71.938 mm`

### Earlier cq_gears attempt before fit retune

These were too large:

- sun OD: `21.875 mm`
- planet OD: about `31.25 mm`
- ring OD: about `98.906 mm`

That mismatch is what triggered the fit-envelope retune.

## Current Partial Run State

- A new run folder exists at:
  - [spur/002](C:/Users/aaron/Documents/c-projects/qdd-gearbox/pygeartrain/step_output_aaron_cq_gears/spur/002)
- That run is **partial only** because the long export was interrupted before completion.
- Files confirmed present in `spur/002`:
  - `mesh_preview_full.png`
  - `mesh_preview_zoom.png`
  - `mesh_preview_contact.png`
  - `mesh_animation.gif`
  - `sun_planet_contact_geometry.png`
- Missing / not yet confirmed from that interrupted run:
  - `sun_planet_contact_slowmo.gif`
  - individual STEP exports
  - final assembly STEP export

Do **not** treat `spur/002` as fully verified.

## Open Technical Questions To Resume With

1. Verify the retuned `cq_gears` set actually exports a valid full assembly STEP after the fit-envelope patch.
2. Measure the retuned involute outputs directly against the original cycloidal parts:
   - sun external diameter
   - planet external diameter
   - ring outer diameter
   - ring inner tip diameter
   - ring root diameter
3. Confirm the involute set still fits the existing carrier / clearance envelope closely enough to avoid a reprint.
4. Tune involute clearance based on the cycloidal clearance intent, instead of only using generic involute backlash values.
5. Confirm the reduction remains the same in the final assembly configuration.

## Recommended Next Steps

1. Re-run [generate_step_aaron_cq_gears.py](C:/Users/aaron/Documents/c-projects/qdd-gearbox/pygeartrain/generate_step_aaron_cq_gears.py) with a long enough timeout to finish the full export.
2. Measure the new retuned run against:
   - [step_output_aaron/spur/000](C:/Users/aaron/Documents/c-projects/qdd-gearbox/pygeartrain/step_output_aaron/spur/000)
   - [skeleton-step-current-state.md](C:/Users/aaron/Documents/c-projects/qdd-gearbox/docs/catia/skeleton-step-current-state.md)
3. If the diameters are close enough, document the fit delta explicitly in [2026-04-17_cq-gears-qdd-generator.md](C:/Users/aaron/Documents/c-projects/qdd-gearbox/pygeartrain/docs/design_log/2026-04-17_cq-gears-qdd-generator.md).
4. Then tune involute clearance using the cycloidal reference clearances and re-export the assembly STEP plus diagnostic GIFs.

## Practical Resume Note

If the goal is to avoid reprinting the carrier, the dimensions that matter most are:

- planet OD
- ring OD
- ring inner tooth envelope
- carrier orbit radius

The retune in the script was specifically aimed at those fit-critical dimensions.

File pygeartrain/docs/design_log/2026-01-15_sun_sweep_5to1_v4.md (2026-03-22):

# 2026-01-15 - Sun Gear Sweep v4 (b Parameter Sweep, N≥3 Only)

## Iteration ID
`2026-01-15_sun_sweep_5to1_v4`

## What Changed from v3

1. **Discarded N=2 configurations** - Only gearsets with N≥3 kept
2. **Swept b parameter** from 0.30 to 0.45 for each valid gearset
3. **2 panels output** - One per gearset, each showing 4 b values

## Valid Gearsets (N≥3 from v3)

| Gearset | S | P | R | N | Ratio |
|---|---|---|---|---|---|
| A | 4 | 6 | 16 | 4 | 5.00:1 |
| B | 6 | 9 | 24 | 3 | 5.00:1 |

## Discarded Gearsets (N=2 only)

| S | P | R | N | Reason |
|---|---|---|---|---|
| 5 | 8 | 21 | 2 | Only N=2 valid, discarded |
| 7 | 10 | 27 | 2 | Only N=2 valid, discarded |

## b Parameter Sweep Results

### Gearset A: S=4, P=6, R=16, N=4

| b | Valid | Overlap% | Tooth Height |
|---|---|---|---|
| 0.30 | YES | 0.00% | Shortest |
| 0.35 | YES | 0.00% | Short |
| 0.40 | YES | 0.00% | Medium |
| 0.45 | YES | 0.00% | Taller |

**File:** `2026-01-15_sun_sweep_5to1_v4_S4_P6_R16_N4_b_sweep.png`

### Gearset B: S=6, P=9, R=24, N=3

| b | Valid | Overlap% | Tooth Height |
|---|---|---|---|
| 0.30 | YES | 0.00% | Shortest |
| 0.35 | YES | 0.00% | Short |
| 0.40 | YES | 0.00% | Medium |
| 0.45 | YES | 0.00% | Taller |

**File:** `2026-01-15_sun_sweep_5to1_v4_S6_P9_R24_N3_b_sweep.png`

## Visual Comparison

Both gearsets are valid across the entire b range (0.30-0.45). The visual differences:

- **b=0.30:** Shortest teeth, most clearance between gears
- **b=0.35:** Slightly taller teeth
- **b=0.40:** Medium tooth height
- **b=0.45:** Tallest teeth in the optimal range

## Locked Gear Configuration

**RING LOCKED** | Sun (input) → Carrier (output) | Ratio = 5.00:1

## Files Generated

```
design_log/
├── 2026-01-15_sun_sweep_5to1_v4.md                        # This file
├── 2026-01-15_sun_sweep_5to1_v4_S4_P6_R16_N4_b_sweep.png  # Gearset A
├── 2026-01-15_sun_sweep_5to1_v4_S6_P9_R24_N3_b_sweep.png  # Gearset B
└── v4_archived_*/                                          # Previous v4 attempts
```

## Recommendations

Both gearsets work well across the b=0.30-0.45 range:

- **For maximum clearance:** Use b=0.30
- **For balanced profile:** Use b=0.35-0.40
- **For taller teeth (more contact):** Use b=0.45

**Gearset A (N=4)** provides better load distribution.
**Gearset B (N=3)** is simpler with fewer parts.

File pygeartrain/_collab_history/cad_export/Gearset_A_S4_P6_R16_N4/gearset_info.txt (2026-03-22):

Gearset: Gearset_A
Configuration: Ring Locked, Sun Input, Carrier Output
Ratio: 5.00:1

Gear Parameters:
  Sun teeth (S): 4
  Planet teeth (P): 6
  Ring teeth (R): 16
  Number of planets (N): 4
  Tooth profile (b): 0.35

Physical Dimensions:
  Ring outer diameter: 70.0 mm
  Gear thickness: 10.0 mm
  Carrier path radius: 20.9654 mm

Files:
  ring_z0.txt, ring_z_top.txt, ring_z_bot.txt - Ring gear profiles
  planet_z0.txt, planet_z_top.txt, planet_z_bot.txt - Planet gear profile (one, pattern for others)
  sun_z0.txt, sun_z_top.txt, sun_z_bot.txt - Sun gear profiles
  carrier_path.txt - Circle for carrier/planet centers
  planet_centers.txt - XYZ positions of planet gear centers

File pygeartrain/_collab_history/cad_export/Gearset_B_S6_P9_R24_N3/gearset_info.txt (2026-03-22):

Gearset: Gearset_B
Configuration: Ring Locked, Sun Input, Carrier Output
Ratio: 5.00:1

Gear Parameters:
  Sun teeth (S): 6
  Planet teeth (P): 9
  Ring teeth (R): 24
  Number of planets (N): 3
  Tooth profile (b): 0.35

Physical Dimensions:
  Ring outer diameter: 70.0 mm
  Gear thickness: 10.0 mm
  Carrier path radius: 21.2671 mm

Files:
  ring_z0.txt, ring_z_top.txt, ring_z_bot.txt - Ring gear profiles
  planet_z0.txt, planet_z_top.txt, planet_z_bot.txt - Planet gear profile (one, pattern for others)
  sun_z0.txt, sun_z_top.txt, sun_z_bot.txt - Sun gear profiles
  carrier_path.txt - Circle for carrier/planet centers
  planet_centers.txt - XYZ positions of planet gear centers

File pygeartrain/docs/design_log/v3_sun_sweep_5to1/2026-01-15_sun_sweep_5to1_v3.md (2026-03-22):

# 2026-01-15 - Sun Gear Sweep v3 (Validated with Polygon Intersection)

## Iteration ID
`2026-01-15_sun_sweep_5to1_v3`

## Critical Discovery: The b Parameter

**ROOT CAUSE OF v1/v2 FAILURES:**
The `b` parameter controls the ratio of epicycloid to hypocycloid in the tooth profile.
- `b=0.8` (used in v1/v2): Creates tall teeth that overlap
- `b=0.5` (v3): Creates shorter teeth that mesh properly

This was discovered through Shapely polygon intersection analysis showing:
- S=4, P=6, R=16, N=3 with b=0.8: **5.68% sun-planet overlap** (INVALID)
- S=4, P=6, R=16, N=4 with b=0.5: **0.00% overlap** (VALID)

## Validation Methodology

Created `gear_validator.py` and `find_valid_gears.py` modules that:

1. **Convert gear profiles to Shapely polygons**
2. **Check polygon intersection area** between:
   - Sun gear and each planet gear
   - Planet gears with each other
3. **Test multiple rotation phases** (0, 0.25, 0.5) to catch worst-case positions
4. **Accept configurations with <1% overlap** (allows numerical tolerance)

### Validation Code Summary
```python
def check_overlap(S, P, R, N, b):
    # Get Shapely polygons from gear profiles
    sun_poly, planet_polys, ring_poly = get_polygons(S, P, R, N, b, phase)

    # Check sun-planet intersection
    intersection = sun_poly.intersection(planet_poly)
    overlap_pct = (intersection.area / sun_poly.area) * 100

    # Valid if overlap < 1%
    return overlap_pct < 1.0
```

## Design Rules Discovered

### Rule 1: b Parameter Controls Tooth Height
| b Value | Tooth Style | Result |
|---|---|---|
| 0.8 | Tall epicycloidal | Often overlaps |
| 0.7 | Medium-tall | Sometimes overlaps |
| 0.5 | Balanced | Usually valid |
| 0.3 | Short hypocycloidal | Always valid (but weaker) |

**Recommendation:** Use `b=0.5` as default for safe meshing.

### Rule 2: Sun-Planet Overlap is the Critical Check
Previous checks focused on planet-to-planet spacing. The actual failure mode is:
- **Planet teeth cutting through sun teeth**
- Visible as filled polygon intersection area > 0

### Rule 3: More Teeth = More Flexibility
Larger sun gears (more teeth) allow more planets and higher b values:
- S=4: Only N=4 or N=2 work
- S=5: Only N=2 works
- S=6: N=2 or N=3 work (sweet spot)
- S=7+: Generally N=2 works

### Rule 4: Even Sun Teeth Give Exact 5:1 Ratio
For ratio = (R+S)/S = 5, need R = 4S.
With R = S + 2P constraint: P = 1.5S (integer only when S is even).

## Locked Gear Configuration

**RING LOCKED, SUN INPUT, CARRIER OUTPUT**

| Element | Role | Connection |
|---|---|---|
| Ring | LOCKED | Bolted to housing/frame |
| Sun | INPUT | Connected to motor shaft |
| Carrier | OUTPUT | Connected to load |

**Ratio Formula:** `(R + S) / S = 1 + R/S`

Other configurations produce different ratios (see v2 documentation).

## Validated Configurations (v3)

All configurations below have **0% sun-planet overlap** verified by Shapely.

### Config 1: S=4, P=6, R=16, N=4, b=0.5
- **Ratio:** 5.00:1 (exact)
- **Planets:** 4 (highest count at this ratio)
- **Sun-Planet Overlap:** 0.00%
- **Note:** Most compact option, good load distribution
- **File:** `2026-01-15_sun_sweep_5to1_v3_S4_P6_R16_N4_b0.5_ratio5.00.png`

### Config 2: S=5, P=8, R=21, N=2, b=0.5
- **Ratio:** 5.20:1
- **Planets:** 2 (only valid option for S=5)
- **Sun-Planet Overlap:** 0.00%
- **Note:** N=3,4 have overlap even with b=0.5
- **File:** `2026-01-15_sun_sweep_5to1_v3_S5_P8_R21_N2_b0.5_ratio5.20.png`

### Config 3: S=6, P=9, R=24, N=3, b=0.5 (RECOMMENDED)
- **Ratio:** 5.00:1 (exact)
- **Planets:** 3 (good balance)
- **Sun-Planet Overlap:** 0.00%
- **Note:** Works with any b from 0.3-0.7, most flexible config
- **File:** `2026-01-15_sun_sweep_5to1_v3_S6_P9_R24_N3_b0.5_ratio5.00.png`

### Config 4: S=7, P=10, R=27, N=2, b=0.5
- **Ratio:** 4.86:1
- **Planets:** 2 (only valid option for S=7)
- **Sun-Planet Overlap:** 0.00%
- **Note:** Larger teeth, potentially smoother operation
- **File:** `2026-01-15_sun_sweep_5to1_v3_S7_P10_R27_N2_b0.5_ratio4.86.png`

## Summary Table

| S | P | R | N | b | Ratio | Overlap | Status |
|---|---|---|---|---|---|---|---|
| 4 | 6 | 16 | 4 | 0.5 | 5.00:1 | 0.00% | VALID |
| 5 | 8 | 21 | 2 | 0.5 | 5.20:1 | 0.00% | VALID |
| 6 | 9 | 24 | 3 | 0.5 | 5.00:1 | 0.00% | VALID (BEST) |
| 7 | 10 | 27 | 2 | 0.5 | 4.86:1 | 0.00% | VALID |

## Comparison: v2 vs v3

| Config | v2 (b=0.8) | v3 (b=0.5) |
|---|---|---|
| S=4, N=3 | 5.68% overlap (INVALID) | - |
| S=4, N=4 | Not tested | 0% overlap (VALID) |
| S=5, N=3 | 4.86% overlap (INVALID) | - |
| S=5, N=2 | - | 0% overlap (VALID) |
| S=6, N=3 | 0% overlap (VALID) | 0% overlap (VALID) |
| S=7, N=3 | 2.33% overlap (MARGINAL) | - |
| S=7, N=2 | - | 0% overlap (VALID) |

## Files Created

### Validation Tools
- `gear_validator.py` - Shapely-based polygon intersection checker
- `find_valid_gears.py` - Configuration search with validation
- `debug_overlap.py` - Visual debugging of overlap issues

### Generated PNGs (in design_log/)
```
2026-01-15_sun_sweep_5to1_v3_S4_P6_R16_N4_b0.5_ratio5.00.png
2026-01-15_sun_sweep_5to1_v3_S5_P8_R21_N2_b0.5_ratio5.20.png
2026-01-15_sun_sweep_5to1_v3_S6_P9_R24_N3_b0.5_ratio5.00.png
2026-01-15_sun_sweep_5to1_v3_S7_P10_R27_N2_b0.5_ratio4.86.png
```

### Debug Images
```
debug_S4_P6_R16_N3.png - Shows 5.68% overlap (why N=3 fails)
debug_S4_P6_R16_N4.png - Shows 0% overlap (why N=4 works with b=0.5)
debug_S5_P8_R21_N3.png
debug_S6_P9_R24_N3.png - Clean meshing
debug_S7_P10_R27_N3.png
```

## Recommendations

1. **For exact 5:1 ratio:** Use S=6, P=9, R=24, N=3, b=0.5
   - Best balance of compactness, load sharing, and flexibility
   - Works with b values from 0.3 to 0.7

2. **For most planets (load distribution):** Use S=4, P=6, R=16, N=4, b=0.5
   - 4 planets give best load sharing
   - Most compact design
   - Requires b ≤ 0.7

3. **For larger teeth (potentially smoother):** Consider S=8+ configurations
   - More teeth generally means smoother operation
   - See `find_valid_gears.py` output for options

## Next Steps

- Test different b values to optimize tooth strength vs clearance
- Animate validated configs to verify smooth rotation
- Export to CAD for manufacturing
- Consider compound planetary for higher ratios

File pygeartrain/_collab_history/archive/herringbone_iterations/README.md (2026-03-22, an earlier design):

# Herringbone Planetary Iterations Archive

This folder contains failed and intermediate attempts at generating correct herringbone planetary gear geometry.

## Summary of Iterations

| Version | Approach | Result | Lesson |
|---|---|---|---|
| v2 | arrange() pre-positioning | Worse - twist around wrong center | Planets must twist around their own centers |
| v3 | Mesh rotation + standard twist | Sun-planet OK, planet-ring misaligned | Different rotation centers cause drift |
| v4 | Gear ratio twist compensation | Worse | Don't trust theoretical formulas blindly |
| v5 | Same reference radius | Worse | - |
| v6 | 1.37° compensation | Wrong direction | - |
| v7 | Mesh axis alignment | Broke sun-planet | Don't change what's working |
| v8 | 2.74° then 4.11° ring comp | Kept getting worse | - |
| v9 | Sweep approach | Found ~0.34° neighborhood | Use empirical search when theory fails |
| v10 | error/4 formula = 0.341° | Overshot, 0.131° remaining | Formula is approximation |
| v11 | Measured 0.21° | Close, 0.0007° remaining | Measure and iterate |
| v12 | Iterated to 0.21068° | Perfect, 0° offset | Final working value |

## Key Lessons

1. **Isolate changes** - Only modify what's broken
2. **Validate empirically** - Theory gives estimates, measurement gives truth
3. **Use visual sweeps** - When stuck, create parameter sweeps
4. **Understand geometry** - Ring compensation needed because planets orbit at offset
5. **Iterate to precision** - Formula → Measure → Adjust → Repeat

## Final Formula

```
ring_compensation = z × tan(helix) × (1/ring_inner_r - 1/mesh_radius)
```

Gets within ~0.005° of perfect. One iteration of measurement refinement achieves 0°.

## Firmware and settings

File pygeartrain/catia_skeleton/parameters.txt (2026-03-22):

# Planetary Gearbox Skeleton Parameters
# Lines starting with # are comments
# Format: ParameterName=Value

# General Parameters
Module=2
FaceWidth=15
PlanetCount=3

# Sun Gear
SunPitchDiameter=40
SunTeeth=20

# Planet Gear
PlanetPitchDiameter=60
PlanetTeeth=30

# Ring Gear
RingPitchDiameter=160
RingTeeth=80
RingWallThickness=10

# Carrier (optional, set to 0 to skip)
CarrierDiameter=150
CarrierThickness=8

# Axial Positions (Z offset from origin)
GearZPosition=0
CarrierZPosition=-10

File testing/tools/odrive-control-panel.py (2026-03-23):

"""
ODrive Control Panel — QDD Test Sessions
Tkinter GUI for safe motor control and live telemetry.

All values shown in OUTPUT SHAFT units (after gear ratio).
ODrive commands are in motor shaft units — conversions happen internally.

Two-tier limits:
  ABSOLUTE MAX — hardcoded safety ceiling, cannot be exceeded
  USER MAX     — adjustable in GUI, sets slider range

Safety features:
- E-stop button (spacebar / Escape) -> immediate IDLE
- Closing window -> automatic IDLE
- All sliders default to zero
- Must explicitly enter closed-loop before any motion
- Current limit enforced on ODrive at connect and on change

Equations (motor -> output):
  Motor Torque (Nm) = Kt * Iq      (Kt = 8.27 / 150KV = 0.0551 Nm/A)
  Output Torque     = Motor Torque * gear_ratio
  Output Speed      = Motor t/s * 60 / gear_ratio  (RPM)
  Output Position   = Motor turns * 360 / gear_ratio  (deg)
"""

import tkinter as tk
from tkinter import ttk
import threading
import time

# --- Absolute Limits (hardcoded safety ceiling) ---
ABS_MAX_MOTOR_VEL = 5.0    # motor t/s — PID stability limit (FW 0.5.5)
ABS_MAX_CURRENT = 19.0     # A — ODrive software limit for D6374
ABS_MAX_GEAR_RATIO = 20.0  # sanity cap

# --- Defaults ---
DEFAULT_GEAR_RATIO = 5.0
DEFAULT_CURRENT_LIM = 10.0        # A
DEFAULT_MAX_OUTPUT_RPM = 60.0     # RPM at output
DEFAULT_MOVE_SPEED_RPM = 30.0     # RPM for position moves
ABS_MAX_MOVE_RPM = 300.0          # Position mode can go faster than vel PID limit
KT = 0.0551                       # Nm/A (8.27 / 150KV)
POLL_RATE_MS = 100

# PID gains
GAINS_GEARBOX = {"pos": 15.0, "vel": 0.1, "int": 0.2, "ramp": 10.0}
GAINS_BARE = {"pos": 5.0, "vel": 0.05, "int": 0.05, "ramp": 3.0}

# State names
STATE_NAMES = {
    0: "UNDEFINED", 1: "IDLE", 2: "STARTUP", 3: "FULL_CAL",
    4: "MOTOR_CAL", 6: "ENC_INDEX", 7: "ENC_OFFSET",
    8: "CLOSED_LOOP", 9: "LOCKIN_SPIN", 10: "LOCKIN_RAMP",
}


class ODriveControlPanel:
    def __init__(self, root):
        self.root = root
        self.root.title("ODrive Control Panel — QDD Testing")
        self.root.protocol("WM_DELETE_WINDOW", self.on_close)
        self.root.bind("<space>", lambda e: self.estop())
        self.root.bind("<Escape>", lambda e: self.estop())

        self.odrv = None
        self.connected = False
        self.in_closed_loop = False
        self.polling = False

        self.build_ui()

    # --- Helpers ---
    def gear_ratio(self):
        try:
            r = float(self.gear_ratio_var.get())
            return max(1.0, min(ABS_MAX_GEAR_RATIO, r))
        except (ValueError, tk.TclError):
            return DEFAULT_GEAR_RATIO

    def is_gearbox(self):
        return self.config_var.get() == "gearbox"

    def ratio(self):
        return self.gear_ratio() if self.is_gearbox() else 1.0

    def current_limit(self):
        try:
            return max(1.0, min(ABS_MAX_CURRENT, float(self.current_lim_var.get())))
        except (ValueError, tk.TclError):
            return DEFAULT_CURRENT_LIM

    def max_output_rpm(self):
        try:
            user_rpm = max(1.0, float(self.max_rpm_var.get()))
        except (ValueError, tk.TclError):
            user_rpm = DEFAULT_MAX_OUTPUT_RPM
        # Clamp to absolute max
        abs_max_rpm = ABS_MAX_MOTOR_VEL * 60.0 / self.ratio()
        return min(user_rpm, abs_max_rpm)

    def max_output_torque(self):
        return KT * self.current_limit() * self.ratio()

    def move_speed_motor_tps(self):
        try:
            rpm = max(1.0, float(self.move_speed_var.get()))
        except (ValueError, tk.TclError):
            rpm = DEFAULT_MOVE_SPEED_RPM
        rpm = min(rpm, ABS_MAX_MOVE_RPM)
        return rpm * self.ratio() / 60.0  # convert output RPM to motor t/s

    # --- UI ---
    def build_ui(self):
        top = ttk.Frame(self.root)
        top.pack(fill="x", padx=10, pady=5)

        # --- Connection ---
        conn = ttk.LabelFrame(top, text="Connection", padding=8)
        conn.pack(side="left", fill="both", expand=True, padx=(0, 5))

        row0 = ttk.Frame(conn)
        row0.pack(fill="x")
        self.btn_connect = ttk.Button(row0, text="Connect", command=self.connect)
        self.btn_connect.pack(side="left", padx=5)
        self.lbl_status = ttk.Label(row0, text="Disconnected", foreground="red")
        self.lbl_status.pack(side="left", padx=10)

        row1 = ttk.Frame(conn)
        row1.pack(fill="x", pady=(5, 0))
        self.config_var = tk.StringVar(value="gearbox")
        ttk.Radiobutton(row1, text="Gearbox", variable=self.config_var, value="gearbox").pack(side="left", padx=5)
        ttk.Radiobutton(row1, text="Bare Motor", variable=self.config_var, value="bare").pack(side="left", padx=5)
        ttk.Label(row1, text="Ratio:").pack(side="left", padx=(15, 2))
        self.gear_ratio_var = tk.StringVar(value=str(DEFAULT_GEAR_RATIO))
        ttk.Entry(row1, textvariable=self.gear_ratio_var, width=5).pack(side="left")
        ttk.Label(row1, text=":1").pack(side="left")

        # --- Limits ---
        lim = ttk.LabelFrame(top, text="Limits (adjustable)", padding=8)
        lim.pack(side="left", fill="both", expand=True, padx=(5, 0))

        def lim_row(parent, label, var, unit, abs_max_text, row):
            ttk.Label(parent, text=label).grid(row=row, column=0, sticky="e", padx=2)
            ttk.Entry(parent, textvariable=var, width=7).grid(row=row, column=1, padx=2)
            ttk.Label(parent, text=unit).grid(row=row, column=2, sticky="w", padx=2)
            ttk.Label(parent, text=f"(abs max: {abs_max_text})", font=("Arial", 7), foreground="gray").grid(row=row, column=3, sticky="w", padx=5)

        abs_max_vel_rpm = ABS_MAX_MOTOR_VEL * 60.0 / DEFAULT_GEAR_RATIO
        self.max_rpm_var = tk.StringVar(value=str(int(DEFAULT_MAX_OUTPUT_RPM)))
        self.current_lim_var = tk.StringVar(value=str(DEFAULT_CURRENT_LIM))
        self.move_speed_var = tk.StringVar(value=str(int(DEFAULT_MOVE_SPEED_RPM)))

        lim_row(lim, "Vel Max:", self.max_rpm_var, "RPM", f"{abs_max_vel_rpm:.0f} RPM (vel PID limit)", 0)
        lim_row(lim, "Current Limit:", self.current_lim_var, "A", f"{ABS_MAX_CURRENT:.0f}A", 1)
        lim_row(lim, "Move Speed:", self.move_speed_var, "RPM", f"for position Go (up to {ABS_MAX_MOVE_RPM:.0f})", 2)

        self.btn_apply_limits = ttk.Button(lim, text="Apply", command=self.apply_limits)
        self.btn_apply_limits.grid(row=0, column=4, rowspan=3, padx=10, sticky="ns")

        # --- Telemetry ---
        telem = ttk.LabelFrame(self.root, text="Telemetry (live from ODrive)", padding=8)
        telem.pack(fill="x", padx=10, pady=3)

        telem_items = [
            ("Bus", "V"), ("Iq", "A"), ("Motor Torque", "Nm"),
            ("Output Torque", "Nm"), ("Output Speed", "RPM"),
            ("Output Pos", "deg"), ("State", ""), ("Status", ""),
        ]
        self.telem_labels = {}
        for i, (key, unit) in enumerate(telem_items):
            label_text = f"{key} ({unit})" if unit else key
            ttk.Label(telem, text=label_text, font=("Arial", 8)).grid(row=0, column=i, padx=3, sticky="s")
            lbl = ttk.Label(telem, text="--", width=11, relief="sunken", anchor="center", font=("Consolas", 10))
            lbl.grid(row=1, column=i, padx=3, pady=2)
            self.telem_labels[key] = lbl

        # --- Equations ---
        eq = ttk.LabelFrame(self.root, text="How values are calculated", padding=4)
        eq.pack(fill="x", padx=10, pady=1)
        eq_text = (
            "Motor Torque = Kt x Iq  (Kt = 0.0551 Nm/A)  |  "
            "Output Torque = Motor Torque x ratio  |  "
            "Output Speed = Motor t/s x 60 / ratio  |  "
            "Output Pos = Motor turns x 360 / ratio"
        )
        ttk.Label(eq, text=eq_text, font=("Arial", 8), foreground="gray").pack()

        # --- Control ---
        ctrl = ttk.LabelFrame(self.root, text="Control (output shaft units)", padding=8)
        ctrl.pack(fill="x", padx=10, pady=3)

        btn_row = ttk.Frame(ctrl)
        btn_row.pack(fill="x", pady=3)
        self.btn_calibrate = ttk.Button(btn_row, text="Calibrate", command=self.calibrate, state="disabled")
        self.btn_calibrate.pack(side="left", padx=5)
        self.btn_closed_loop = ttk.Button(btn_row, text="Enter Closed Loop", command=self.enter_closed_loop, state="disabled")
        self.btn_closed_loop.pack(side="left", padx=5)
        self.btn_idle = ttk.Button(btn_row, text="IDLE (motor off, spins free)", command=self.go_idle, state="disabled")
        self.btn_idle.pack(side="left", padx=5)

        mode_row = ttk.Frame(ctrl)
        mode_row.pack(fill="x", pady=3)
        ttk.Label(mode_row, text="Mode:").pack(side="left", padx=5)
        self.mode_var = tk.StringVar(value="velocity")
        for text, val in [("Velocity", "velocity"), ("Position", "position"), ("Torque", "torque")]:
            ttk.Radiobutton(mode_row, text=text, variable=self.mode_var, value=val, command=self.on_mode_change).pack(side="left", padx=5)

        # Velocity
        self.vel_frame = ttk.Frame(ctrl)
        ttk.Label(self.vel_frame, text="Speed (RPM):").pack(side="left", padx=5)
        self.vel_slider = tk.Scale(self.vel_frame, from_=-DEFAULT_MAX_OUTPUT_RPM, to=DEFAULT_MAX_OUTPUT_RPM,
                                   resolution=1, orient="horizontal", length=400,
                                   command=self.on_vel_change)
        self.vel_slider.set(0)
        self.vel_slider.pack(side="left", fill="x", expand=True, padx=5)
        ttk.Button(self.vel_frame, text="Zero", command=lambda: self.vel_slider.set(0)).pack(side="left", padx=5)
        self.vel_frame.pack(fill="x", pady=3)

        # Position
        self.pos_frame = ttk.Frame(ctrl)
        ttk.Label(self.pos_frame, text="Position (deg):").pack(side="left", padx=5)
        self.pos_entry = ttk.Entry(self.pos_frame, width=10)
        self.pos_entry.insert(0, "0")
        self.pos_entry.pack(side="left", padx=5)
        ttk.Button(self.pos_frame, text="Go", command=self.go_to_position).pack(side="left", padx=5)
        self.lbl_move_speed = ttk.Label(self.pos_frame, text=f"(at {int(DEFAULT_MOVE_SPEED_RPM)} RPM)", font=("Arial", 8), foreground="gray")
        self.lbl_move_speed.pack(side="left", padx=5)

        # Torque
        self.torque_frame = ttk.Frame(ctrl)
        ttk.Label(self.torque_frame, text="Torque (Nm):").pack(side="left", padx=5)
        max_t = KT * DEFAULT_CURRENT_LIM * DEFAULT_GEAR_RATIO
        self.torque_slider = tk.Scale(self.torque_frame, from_=-max_t, to=max_t,
                                      resolution=0.05, orient="horizontal", length=400,
                                      command=self.on_torque_change)
        self.torque_slider.set(0)
        self.torque_slider.pack(side="left", fill="x", expand=True, padx=5)
        ttk.Button(self.torque_frame, text="Zero", command=lambda: self.torque_slider.set(0)).pack(side="left", padx=5)

        # --- E-STOP ---
        estop_frame = ttk.Frame(self.root, padding=5)
        estop_frame.pack(fill="x", padx=10, pady=3)
        self.btn_estop = tk.Button(estop_frame, text="E-STOP (spacebar)",
                                   command=self.estop, bg="red", fg="white",
                                   font=("Arial", 14, "bold"), height=2)
        self.btn_estop.pack(fill="x")

        # --- Status bar ---
        self.status_bar = ttk.Label(self.root, text="Press Connect. IDLE = motor off, spins freely. E-STOP: spacebar/Escape.",
                                     relief="sunken", anchor="w", padding=4)
        self.status_bar.pack(fill="x", padx=10, pady=(0, 5))

    def log(self, msg):
        self.status_bar.config(text=msg)

    def apply_limits(self):
        """Apply user limits — update slider ranges and ODrive current limit."""
        # Update velocity slider range
        rpm = self.max_output_rpm()
        self.vel_slider.config(from_=-rpm, to=rpm)
        if abs(self.vel_slider.get()) > rpm:
            self.vel_slider.set(0)
            if self.connected and self.in_closed_loop:
                self.odrv.axis0.controller.input_vel = 0

        # Update torque slider range
        max_t = self.max_output_torque()
        self.torque_slider.config(from_=-max_t, to=max_t)
        if abs(self.torque_slider.get()) > max_t:
            self.torque_slider.set(0)
            if self.connected and self.in_closed_loop:
                self.odrv.axis0.controller.input_torque = 0

        # Update move speed label
        try:
            ms = float(self.move_speed_var.get())
        except ValueError:
            ms = DEFAULT_MOVE_SPEED_RPM
        self.lbl_move_speed.config(text=f"(at {int(ms)} RPM)")

        # Push current limit to ODrive
        if self.connected:
            cl = self.current_limit()
            self.odrv.axis0.motor.config.current_lim = cl
            self.log(f"Limits applied. Speed: ±{rpm:.0f} RPM, Current: {cl:.1f}A, Torque: ±{max_t:.2f} Nm, Move: {int(ms)} RPM")
        else:
            self.log(f"Limits updated. Speed: ±{rpm:.0f} RPM, Current: {self.current_limit():.1f}A. Connect to apply to ODrive.")

    # --- Connection ---
    def connect(self):
        if self.connected:
            return
        self.log("Connecting... please wait (can take up to 60s)")
        self.btn_connect.config(state="disabled")

        def do_connect():
            try:
                import odrive
                self.root.after(0, lambda: self.lbl_status.config(text="Scanning USB...", foreground="orange"))
                self.odrv = odrive.find_any(timeout=90)

                # Enforce current limit
                self.odrv.axis0.motor.config.current_lim = self.current_limit()

                # Set gains
                gains = GAINS_GEARBOX if self.is_gearbox() else GAINS_BARE
                ax = self.odrv.axis0
                ax.controller.config.pos_gain = gains["pos"]
                ax.controller.config.vel_gain = gains["vel"]
                ax.controller.config.vel_integrator_gain = gains["int"]
                ax.controller.config.vel_ramp_rate = gains["ramp"]

                # Set trap trajectory limits for position mode
                ax.trap_traj.config.vel_limit = self.move_speed_motor_tps()
                ax.trap_traj.config.accel_limit = 10.0
                ax.trap_traj.config.decel_limit = 10.0

                self.connected = True
                self.root.after(0, self._on_connected)
            except Exception as e:
                self.root.after(0, lambda: self._on_connect_fail(str(e)))

        threading.Thread(target=do_connect, daemon=True).start()

    def _on_connected(self):
        bus = self.odrv.vbus_voltage
        config = f"gearbox {self.gear_ratio():.0f}:1" if self.is_gearbox() else "bare motor"
        self.lbl_status.config(text=f"Connected ({config}) — {bus:.1f}V", foreground="green")
        self.btn_connect.config(state="disabled")
        self.btn_calibrate.config(state="normal")
        self.btn_closed_loop.config(state="normal")
        self.btn_idle.config(state="normal")
        self.apply_limits()
        self.start_polling()

    def _on_connect_fail(self, err):
        self.lbl_status.config(text="Connection failed", foreground="red")
        self.btn_connect.config(state="normal")
        self.log(f"Connection failed: {err}")

    # --- Telemetry ---
    def start_polling(self):
        if self.polling:
            return
        self.polling = True
        self._poll()

    def _poll(self):
        if not self.polling or not self.connected:
            return
        try:
            ax = self.odrv.axis0
            iq = ax.motor.current_control.Iq_measured
            motor_vel = ax.encoder.vel_estimate
            motor_pos = ax.encoder.pos_estimate

            r = self.ratio()
            motor_torque = KT * iq
            output_torque = motor_torque * r
            output_rpm = motor_vel * 60.0 / r
            output_deg = motor_pos * 360.0 / r

            state_num = ax.current_state
            state_name = STATE_NAMES.get(state_num, f"?{state_num}")

            self.telem_labels["Bus"].config(text=f"{self.odrv.vbus_voltage:.1f}")
            self.telem_labels["Iq"].config(text=f"{iq:.2f}")
            self.telem_labels["Motor Torque"].config(text=f"{motor_torque:.3f}")
            self.telem_labels["Output Torque"].config(text=f"{output_torque:.3f}")
            self.telem_labels["Output Speed"].config(text=f"{output_rpm:.1f}")
            self.telem_labels["Output Pos"].config(text=f"{output_deg:.1f}")
            self.telem_labels["State"].config(text=state_name)

            errs = ax.error | ax.motor.error | ax.encoder.error
            if errs:
                self.telem_labels["Status"].config(text=f"ERR:{errs}", foreground="red")
            else:
                self.telem_labels["Status"].config(text="OK", foreground="green")
        except Exception:
            self.telem_labels["Status"].config(text="COMM ERR", foreground="red")

        self.root.after(POLL_RATE_MS, self._poll)

    # --- Calibration ---
    def calibrate(self):
        if not self.connected:
            return
        self.log("Calibrating... motor will beep then spin slowly.")
        self.btn_calibrate.config(state="disabled")

        def do_cal():
            try:
                self.odrv.axis0.requested_state = 3
                while self.odrv.axis0.current_state != 1:
                    time.sleep(0.5)
                errs = self.odrv.axis0.error | self.odrv.axis0.motor.error | self.odrv.axis0.encoder.error
                R = self.odrv.axis0.motor.config.phase_resistance * 1000
                L = self.odrv.axis0.motor.config.phase_inductance * 1e6
                if errs:
                    self.root.after(0, lambda: self.log(f"Calibration FAILED. Errors present. R={R:.1f}mOhm L={L:.1f}uH"))
                else:
                    self.root.after(0, lambda: self.log(f"Calibration OK. R={R:.1f}mOhm L={L:.1f}uH. Ready for closed loop."))
            except Exception as e:
                self.root.after(0, lambda: self.log(f"Calibration error: {e}"))
            finally:
                self.root.after(0, lambda: self.btn_calibrate.config(state="normal"))

        threading.Thread(target=do_cal, daemon=True).start()

    # --- Control State ---
    def enter_closed_loop(self):
        if not self.connected:
            return
        try:
            ax = self.odrv.axis0
            ax.controller.input_vel = 0
            ax.controller.input_torque = 0
            ax.controller.config.control_mode = 2  # velocity
            ax.controller.config.input_mode = 1     # passthrough
            self.vel_slider.set(0)
            self.torque_slider.set(0)
            self.mode_var.set("velocity")
            self.on_mode_change()

            ax.requested_state = 8
            time.sleep(0.3)
            if ax.current_state == 8:
                self.in_closed_loop = True
                self.log("Closed loop active. Motor holding position.")
            else:
                self.log(f"Failed to enter closed loop. State: {ax.current_state}")
        except Exception as e:
            self.log(f"Error: {e}")

    def go_idle(self):
        if not self.connected:
            return
        try:
            self.odrv.axis0.controller.input_vel = 0
            self.odrv.axis0.controller.input_torque = 0
            self.odrv.axis0.requested_state = 1
            self.in_closed_loop = False
            self.vel_slider.set(0)
            self.torque_slider.set(0)
            self.log("IDLE — motor off, spins freely.")
        except Exception as e:
            self.log(f"Error going idle: {e}")

    def estop(self):
        try:
            if self.odrv:
                self.odrv.axis0.controller.input_vel = 0
                self.odrv.axis0.controller.input_torque = 0
                self.odrv.axis0.requested_state = 1
                self.in_closed_loop = False
                self.vel_slider.set(0)
                self.torque_slider.set(0)
                self.log("E-STOP — motor off.")
        except Exception:
            self.log("E-STOP — comm error, kill DC power manually!")

    # --- Mode switching ---
    def on_mode_change(self):
        mode = self.mode_var.get()
        self.vel_frame.pack_forget()
        self.pos_frame.pack_forget()
        self.torque_frame.pack_forget()

        if mode == "velocity":
            self.vel_frame.pack(fill="x", pady=3)
            if self.connected and self.in_closed_loop:
                self.odrv.axis0.controller.input_vel = 0
                self.vel_slider.set(0)
                self.odrv.axis0.controller.config.control_mode = 2
                self.odrv.axis0.controller.config.input_mode = 1  # passthrough
        elif mode == "position":
            self.pos_frame.pack(fill="x", pady=3)
            if self.connected and self.in_closed_loop:
                self.odrv.axis0.controller.config.control_mode = 3
                self.odrv.axis0.controller.config.input_mode = 5  # trap trajectory
                # Update trap traj speed
                self.odrv.axis0.trap_traj.config.vel_limit = self.move_speed_motor_tps()
        elif mode == "torque":
            self.torque_frame.pack(fill="x", pady=3)
            if self.connected and self.in_closed_loop:
                self.odrv.axis0.controller.input_torque = 0
                self.torque_slider.set(0)
                self.odrv.axis0.controller.config.control_mode = 1
                self.odrv.axis0.controller.config.input_mode = 1  # passthrough
        self.log(f"Mode: {mode}")

    # --- Command handlers ---
    def on_vel_change(self, val):
        if not self.connected or not self.in_closed_loop:
            return
        try:
            output_rpm = float(val)
            motor_vel = output_rpm * self.ratio() / 60.0
            motor_vel = max(-ABS_MAX_MOTOR_VEL, min(ABS_MAX_MOTOR_VEL, motor_vel))
            self.odrv.axis0.controller.input_vel = motor_vel
        except Exception:
            pass
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

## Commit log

2026-03-01 Aaron's QDD working state: STEP pipeline + docs + folder reorg
    - generate_step_aaron.py: working STEP generation (original v24 loft logic)
    - _PRINT/_CAD naming convention for output files
    - Folder reorg: pygeartrain/ top level cleaned (docs/, tools/, _collab_history/)
    - CATIA integration doc: multi-body part workflow (5-stage)
    - Pipeline README with full explanation
    - .gitignore: exclude generated .stl/.step files
2026-03-01 Export gearbox_CAD.step as multi-body part (not assembly)
    Use OCC STEPControl_Writer directly with write.step.assembly=0
    to prevent compound from being decomposed into assembly structure.
    CATIA should now import as one part with multiple bodies.
2026-03-02 Rotate planet_0 to +Y axis (was +X)
    Added PLANET_0_ANGLE_DEG = 90.0 param. Matches CATIA skeleton
    datum orientation. Easy to change if needed.
2026-03-02 Add CATIA STEP integration workflow plan doc
    Captures current state, constraints, proposed two-part approach
    (gear_set placeholder + gear_output with STEP base), open questions,
    and what not to do. Reference for fresh session.
2026-03-13 feat: add STATE.md for discovery system
    Part of hub-and-spoke project orientation system.
    Standardized project state file — replaces ad-hoc scanning.
    Spec: docs/superpowers/specs/2026-03-13-discovery-system-design.md
2026-03-14 Add spur gear mode and organize output by gear type
    GEAR_TYPE config ('spur', 'herringbone', 'helix') controls twist and
    ring split behavior. Output folders now separated: step_output_aaron/spur/,
    herringbone/, etc. with auto-incrementing run numbers. Spur mode exports
    single-piece ring instead of split halves.
2026-03-21 Add QDD Learning System v2 design spec
    Conversational learning system with 6-step workflow (diagnose, learn,
    distill, practice, grade, drill), gamification (streaks, unlocks,
    dashboard), and /learn skill entry point. Supersedes v1 workbook-only
    approach by adding interactive teaching before assessment.
2026-03-21 feat: populate diagnosed gaps for topics 02-04
    Read existing Part 1 workbook answers and extracted gap lists:
    - Topic 02 (torque-speed): 5 gaps — back-EMF, voltage headroom, speed ceiling
    - Topic 03 (thermal): 5 gaps — heat sources, I-squared, Rth, thermal model
    - Topic 04 (friction): 6 gaps — Coulomb/viscous models, backdrivability
2026-03-22 feat: add progress visualizer, learning system, calculators, and full project structure
    - Progress visualizer dashboard (CustomTkinter) reading progress.json
    - Learning system v2 with 13 topics, 6-step workflow, priority tiers
    - Design calculators (gear geometry, tooth stress, bearing life, thermal)
    - Docs reorganization: archive old numbered docs, add design/, catia/, specs/
    - Test infrastructure, prototype docs, drawings
    - Integrated timeline for spring 2026 learn-apply-ship cycles
    [carrier_bottom A.1.stp, carrier_bottom_REV00A.stp, carrier_bottom_REV00B.stp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]
2026-03-23 feat: first power-on — SOP, control panel GUI, session logging
    - Moved buddy's onboarding guide to testing/hardware/
    - Created SOP with safety checklists, startup sequence, shutdown/emergency procedures
    - Built tkinter control panel: velocity/position/torque modes in output shaft units,
    two-tier limits (user adjustable + absolute max), trap trajectory position control,
    E-stop, auto-IDLE on close
    - Started session log documenting first calibration and spin
    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
2026-04-18 Add isolated involute generator work-in-progress
    Keep the original cycloidal generator untouched and capture the current involute scripts, verification helpers, and design-log note before the next meshing revision.
2026-04-18 Align involute static preview with STEP assembly
    Keep the cycloidal path untouched. Use the solid assembly placement for static involute previews and add a fast sampled-outline audit report for the current static mesh.
2026-05-03 Track Rev01 gear generator baseline
2026-05-03 Add Rev01 bottom taper gear variant
2026-05-04 Document session 007/008 dyno findings + harness fixes; rewrite README
    Test harness fixes (silent failure modes that wasted runs):
    - safe_ramp_test.py / safe_torque_ramp_test.py: in-loop axis_state
    watchdog so silent disarms abort cleanly with disarm_reason logged
    - both scripts: enable_watchdog=False before clear_errors; feed
    watchdog after enabling, before CLOSED_LOOP transition (was tripping
    axis=2048 instantly on retries)
    - both scripts: device-level odrv.clear_errors() in addition to
    per-subobject clears; post-clear error printout
    - run_synced_motor_dyno_temp.ps1: manifest write retry now 20x500ms
    with warn-not-throw, so AV/file-indexer locks no longer orphan
    Python jobs and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
    [safe_ramp_test.py, safe_torque_ramp_test.py]
2026-05-04 Cross-reference dyno findings + recovery procedure in mks docs
    BARE-MOTOR-SETUP.md:
    - Known limit section for the bare-motor torque wall confirmed 2026-05-03
    (loaded direction stalls at 2.8 Nm / 70 A Iq)
    - Three options documented for matched-load baseline (hand-spin,
    current burst, methodology change)
    - Recovery section explaining the new clear/feed/state-watch sequence
    in safe_ramp_test.py / safe_torque_ramp_test.py
    SESSION-CHECKLIST.md:
    - Added Synced Dyno Runs section pointing to OFFICIAL-DYNO-TESTING.md
    - Added After A Failed Run diagnostic flow (post-clear printout,
    in-loop disarm message, manifest exit codes, PSU power-cycle for
    sticky bits)
    Anyone reading the controller-s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

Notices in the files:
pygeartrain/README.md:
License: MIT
